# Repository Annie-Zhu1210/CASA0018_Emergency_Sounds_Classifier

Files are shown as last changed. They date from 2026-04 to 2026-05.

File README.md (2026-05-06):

#  Emergency Sounds Classifier
**CASA0018 Deep Learning for Sensor Networks — Final Project**

A wearable wristband for deaf and hearing-impaired people that detects urban emergency sounds in real time and alerts the user through vibration patterns.

<p align="center">
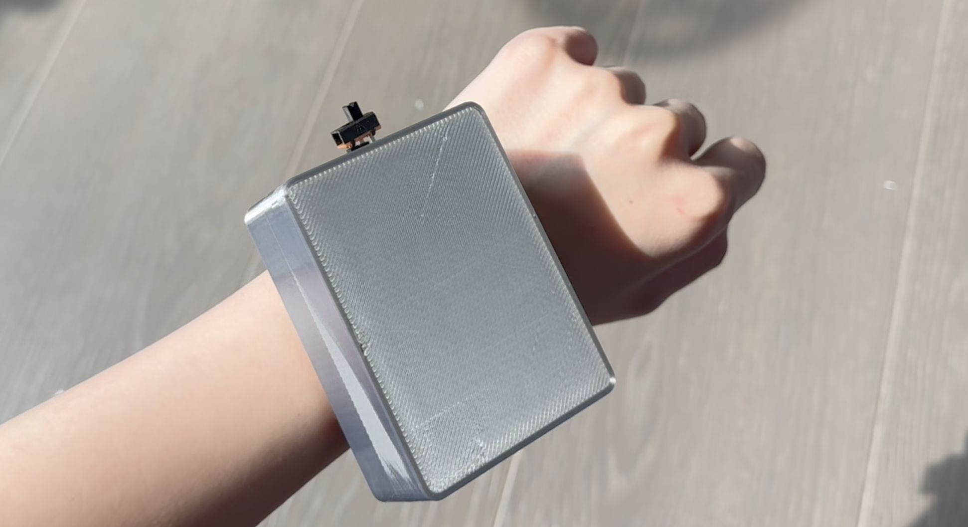
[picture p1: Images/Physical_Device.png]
Wristband
  <br>
</p>

---

## Overview

Approximately 1.57 billion people worldwide experience some degree of hearing loss. In urban environments, this creates real safety risks: failing to detect approaching emergency vehicles or car horns affects both pedestrians and drivers. This project deploys a trained audio classification model on an Arduino Nano 33 BLE Sense Lite, embedded in a 3D-printed wristband. The device listens continuously through its onboard MEMS microphone and triggers different vibration patterns depending on what it hears.

**Three classes are detected:**

| Class | Alert |
|---|---|
| `siren_hilo` | 1800ms sustained vibration pulse |
| `siren_wail&yelp` | 1800ms sustained vibration pulse |
| `carhorn` | Two 400ms pulses with 200ms gap |
| `background` | No vibration |

A confidence threshold of 0.70 is applied — the motor only activates when the model is sufficiently certain.

---

## Hardware

| Component | Spec | Role |
|---|---|---|
| Arduino Nano 33 BLE Sense Lite | 3.7V operating, VIN 4.5–21V | Microphone input, model inference, motor control |
| Vibration Motor Module | 3V–5.3V | Haptic alert output |
| 1000mAh 3.7V LiPo Battery | Nominal 3.7V | Wireless power |
| Adafruit bq24074 Charger | Load output 3.7–4.2V | USB-C charging, power regulation |
| Slide Switch | 0.3A 50V | On/off control |

**Wiring summary:**
- LiPo → bq24074 BATT port
- bq24074 LOAD → Arduino VIN (via slide switch)
- Arduino 3.3V → Motor VCC
- Arduino GND → Motor GND
- Arduino D9 → Motor IN

<p align="center">
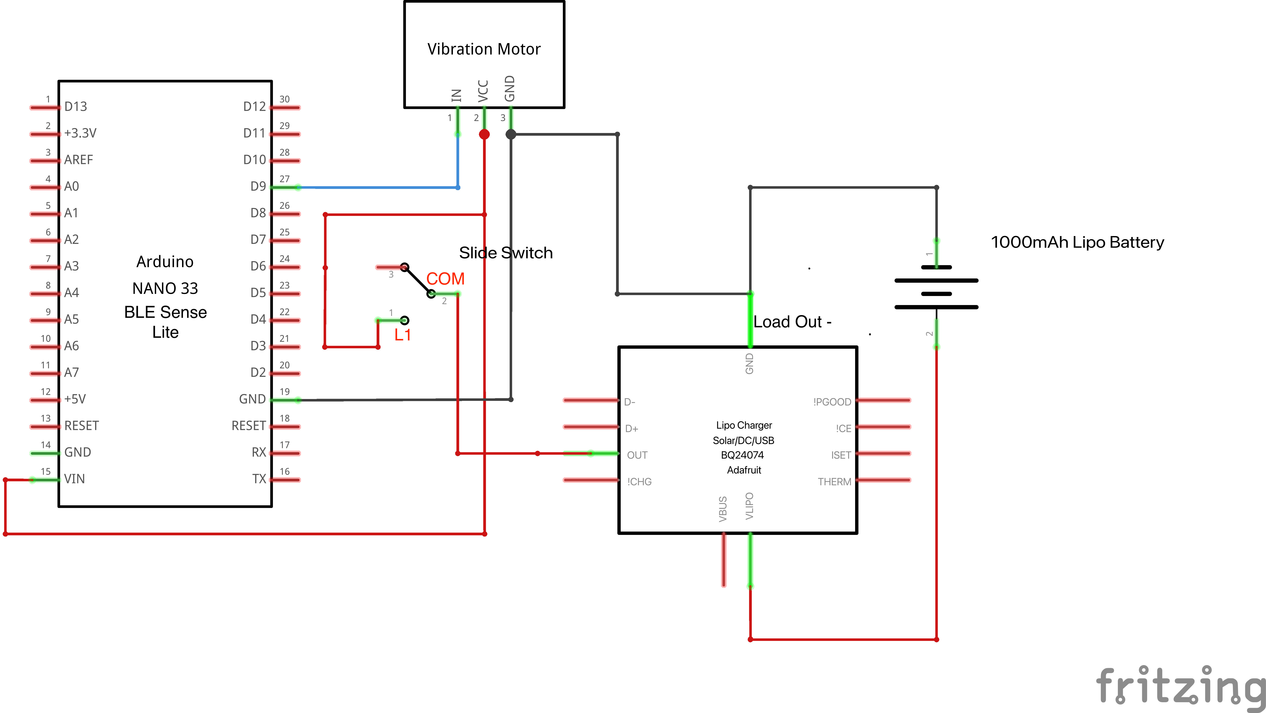
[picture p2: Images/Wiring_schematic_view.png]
Device wiring schematic
  <br>
  <sub>Device wiring schematic</sub>
</p>

**Estimated battery life:** ~83 hours assuming emergency sounds occur 10% of operating time (9mA idle, up to 39mA when motor fires).

---

## Enclosure

Hardware is housed in a custom 3D-printed box attached to a fabric scrunchy to simulate a wristband. The base is 1mm thick to maximise vibration transmission. Two rectangular apertures allow USB-C charging access and slide switch operation. Four corner screws secure the lid.

<p align="center">
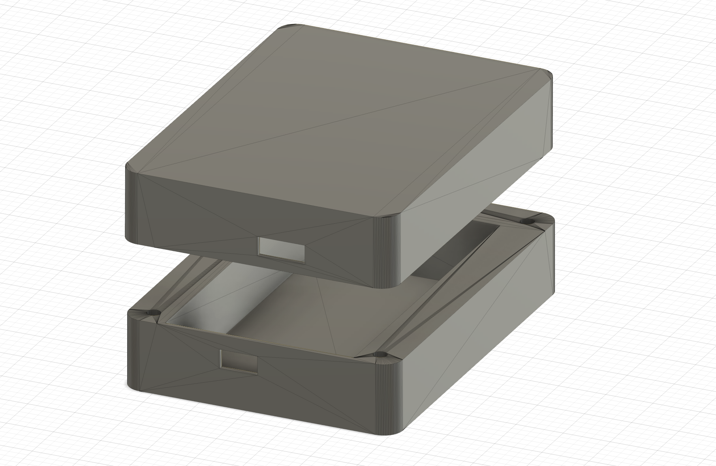
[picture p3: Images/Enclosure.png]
Enclosure 3D model
  <br>
  <sub>Enclosure 3D model</sub>
</p>

---

## Model

**Platform:** Edge Impulse (TensorFlow-based)

**Feature extraction:** Mel-filterbank Energy (MFE) — chosen over MFCCs because MFCCs' cepstral compression discards higher-frequency spectral detail, which is important for siren frequency sweep patterns.

**Architecture:** 1D Convolutional Neural Network
- Input: 2000ms audio window, resampled to 16kHz
- Two 1D conv/pool layers (16 filters, kernel size 3)
- Two dropout layers (rate 0.25)
- Flatten → output layer (4 classes)

**Deployment:** Quantised int8 TensorFlow Lite Arduino library
- RAM: 35.8KB (well within Arduino's 256KB budget)
- Latency: 522ms
- No accuracy loss vs. float32

**Final test accuracy: 94.26%**

| Class | Test Accuracy | F1 Score |
|---|---|---|
| background | 94.1% | 0.94 |
| carhorn | 72.7% | 0.84 |
| siren_hilo | 98.8% | 0.99 |
| siren_wail&yelp | 99.6% | 0.97 |

AUC-ROC: 1.00

---

## Experiment Log

Eight experiments were run iteratively. Key findings:

| Experiment | Key Change | Validation Acc | Test Acc |
|---|---|---|---|
| 1 | Baseline, 6 classes | 98.3% | 33.68% |
| 2 | Removed problematic background recording | 98.4% | 69.73% |
| 3 | 4000ms window, adjusted MFE, removed phaser | 98.1% | 50.26% |
| 4 | Merged wail & yelp, reverted to 2000ms | 97.5% | 91.65% |
| 5 | Increased first conv filters 8 → 16 | 98.3% | 94.54% |
| 6 | Added street-recorded carhorn samples | 99.5% | 70.71% |
| 7 | Added diverse background (traffic, wind) | 97.2% | 74.12% |
| 8 | Added wind and ambience samples — **final model** | 98.7% | 94.26% |

The single largest accuracy gain (+40 percentage points) came from merging `siren_wail` and `siren_yelp` into one class in Experiment 4 — achieved purely through label redesign, with no change to architecture or training parameters.

---

## Data

Audio samples were collected from two sources:

- **Personal recordings** — primarily around central London
- **Freesound.org** — supplementary samples (see [`SampleData/ATTRIBUTIONS.md`](SampleData/ATTRIBUTIONS.md) for full attribution)

All audio was resampled from 44.1kHz to 16kHz to match the Arduino microphone's capture rate before feature extraction.

**Class structure evolved across experiments** — starting with 6 classes (`background`, `carhorn`, `siren_hilo`, `siren_wail`, `siren_yelp`, `siren_phaser`) and consolidating to 4 by the final model. `siren_phaser` was removed due to insufficient data; `siren_wail` and `siren_yelp` were merged because they are acoustically inseparable at any tested window size and require the same user response.

---

## Repository Structure

```
├── Enclosure/
│   └── Bottom.STL                 # Enclosure bottom part
│   └── Top.STL                    # Enclosure top part
├── Siren_Classification/
│   └── Siren_Classification.ino   # Arduino sketch (inference + vibration logic)
├── SampleData/
│   └── ATTRIBUTIONS.md            # Full Freesound sample attribution
│   └── BackgroundNoise/
│   └── CarHorn/ 
│   └── Sirens/
│       └── Yelp/
│       └── Wail/
│       └── Hi-Lo/
│       └── Phaser/
├── model/
│   └── ei-emergencyvehiclesirens-arduino-1.0.1-impulse-6.zip  # Trained model
└── README.md
```

---

## How to Reproduce

### Option A: Use the pre-trained model (recommended)
 
1. Download the pre-trained Arduino library from [`model/ei-emergencyvehiclesirens-arduino-1.0.1-impulse-6.zip`](model/ei-emergencyvehiclesirens-arduino-1.0.1-impulse-6.zip)
2. In Arduino IDE, go to **Sketch → Include Library → Add .ZIP Library** and select the downloaded file
3. Open `Siren_Classification/Siren_Classification.ino` and upload to the Arduino Nano 33 BLE Sense Lite

### Option B: Retrain from scratch

1. **Set up Edge Impulse project** — create a new project and select Arduino Nano 33 BLE Sense as the target device
2. **Upload audio data** — use the Edge Impulse data acquisition tool or upload files directly; resample to 16kHz
3. **Configure impulse** — set window size to 2000ms; select MFE feature extraction with default parameters (frame length 0.02, frame stride 0.01, 40 filters, FFT length 256, noise floor −52dB)
4. **Set neural network architecture** — two 1D conv/pool layers with 16 filters, kernel size 3; dropout 0.25 after each; flatten; 4-class output
5. **Train and test** — target ~73/27 train/test split
6. **Deploy** — export as quantised int8 Arduino library
7. **Flash the sketch** — open `Siren_Classification/Siren_Classification.ino` in Arduino IDE, install the exported library, and upload to the board

---

## Limitations and Future Work

- **Carhorn false negatives (23.4%)** — a short horn in heavy traffic can produce a feature map acoustically similar to road ambience. A larger and more diverse carhorn dataset, particularly distant and overlapping sounds, would address this.
- **Enclosure attenuation** — testing showed that enclosing the device on the wrist reduces microphone sensitivity to distant sounds compared to open-air conditions. Aperture placement or microphone relocation could improve this.
- **Validation vs. test gap** — in experiments 6–7, high validation accuracy was misleading because validation samples did not reflect real-world recording conditions. The held-out test set is the only reliable performance indicator for this type of project.

---

## References

- Bubar et al. (2020). Emergency siren detection technology and hearing impairment: a systematized literature review. *Disability and Rehabilitation: Assistive Technology*.
- Chemnad & Othman (2024). Digital accessibility in the era of artificial intelligence. *Frontiers in Artificial Intelligence*.
- Haile et al. (2021). Hearing loss prevalence and years lived with disability, 1990–2019. *The Lancet*, 397(10278).
- Haytham Fayek (2016). *Speech Processing for Machine Learning: Filter banks, Mel-Frequency Cepstral Coefficients (MFCCs) and What’s In-Between*. 

- Fayek, H. (2016). Speech Processing for Machine Learning: Filter banks, MFCCs and What's In-Between.
- Luque et al. (2018). Optimal Representation of Anuran Call Spectrum in Environmental Monitoring Systems. *Sensors*, 18(6).
- Zayen & Groessing (2025). SafeDrive4Deaf. *Nafath*, 9(29).

---

## Generative AI Disclosure

Claude (Anthropic, Sonnet 4.6) was used during this project for research framing, technical guidance on Edge Impulse and wiring decisions, and report writing assistance. All experimental decisions, data collection, and results are the author's own work. All AI-assisted content was reviewed and verified before inclusion.

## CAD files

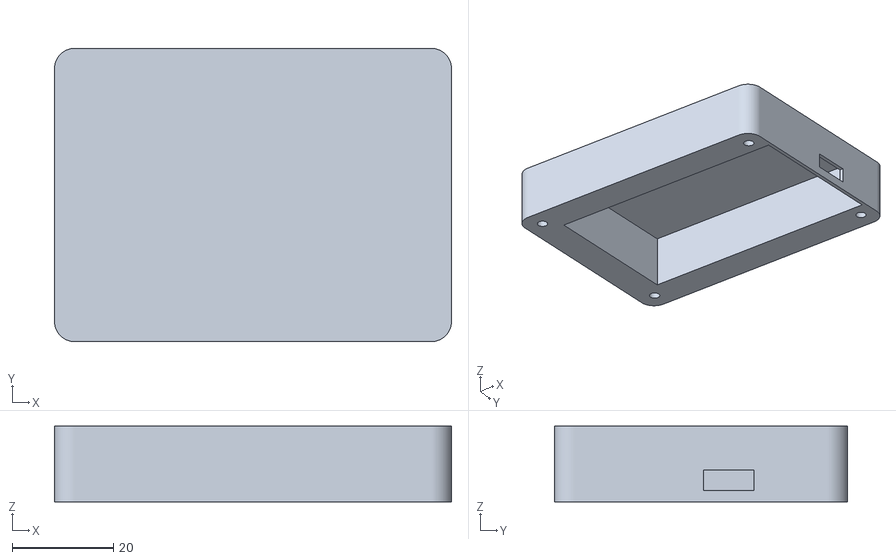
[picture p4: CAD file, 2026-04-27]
Enclosure/Top.STL
78.5 x 58.0 x 15.0

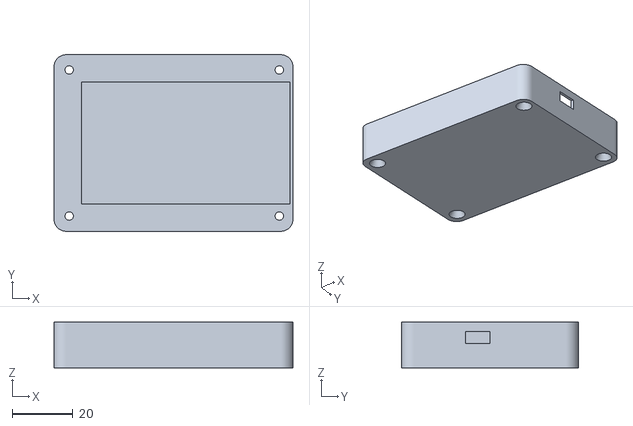
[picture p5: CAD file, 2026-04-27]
Enclosure/Bottom.STL
78.5 x 58.0 x 15.0

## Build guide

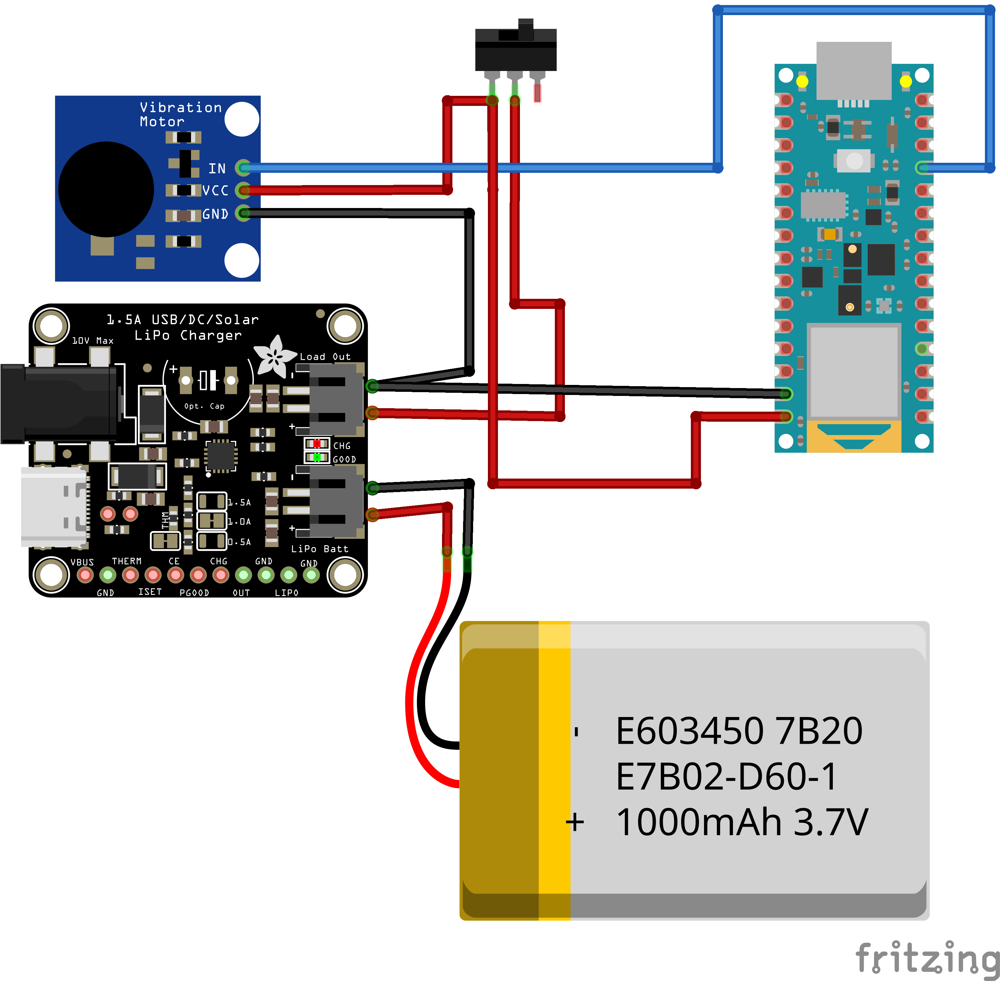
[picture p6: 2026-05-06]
Images/Wiring_breadboard_view.png

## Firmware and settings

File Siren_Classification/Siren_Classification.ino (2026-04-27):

#include <PDM.h>
#include <EmergencyVehicleSirens_inferencing.h>

#define MOTOR_PIN           9
#define CONFIDENCE_THRESHOLD 0.70

// Vibration patterns
#define MODERATE_DURATION   400
#define MODERATE_REPEATS    2
#define INTENSE_DURATION    1800
#define INTENSE_REPEATS     1

/* Audio buffer */
typedef struct {
  int16_t *buffer;
  uint8_t buf_ready;
  uint32_t buf_count;
  uint32_t n_samples;
} inference_t;

static inference_t inference;
static signed short sampleBuffer[2048];
static bool debug_nn = false;

void vibrate_moderate() {
  for (int i = 0; i < MODERATE_REPEATS; i++) {
    digitalWrite(MOTOR_PIN, HIGH);
    delay(MODERATE_DURATION);
    digitalWrite(MOTOR_PIN, LOW);
    delay(200);
  }
}

void vibrate_intense() {
  for (int i = 0; i < INTENSE_REPEATS; i++) {
    digitalWrite(MOTOR_PIN, HIGH);
    delay(INTENSE_DURATION);
    digitalWrite(MOTOR_PIN, LOW);
    delay(200);
  }
}

static void pdm_data_ready_inference_callback(void) {
  int bytesAvailable = PDM.available();
  int bytesRead = PDM.read((char *)&sampleBuffer[0], bytesAvailable);

  if (inference.buf_ready == 0) {
    for (int i = 0; i < bytesRead >> 1; i++) {
      inference.buffer[inference.buf_count++] = sampleBuffer[i];
      if (inference.buf_count >= inference.n_samples) {
        inference.buf_count = 0;
        inference.buf_ready = 1;
        break;
      }
    }
  }
}

static bool microphone_inference_start(uint32_t n_samples) {
  inference.buffer = (int16_t *)malloc(n_samples * sizeof(int16_t));
  if (inference.buffer == NULL) return false;

  inference.buf_count = 0;
  inference.n_samples = n_samples;
  inference.buf_ready = 0;

  PDM.onReceive(pdm_data_ready_inference_callback);
  PDM.setBufferSize(4096);

  if (!PDM.begin(1, EI_CLASSIFIER_FREQUENCY)) {
    ei_printf("ERR: Failed to start PDM!\r\n");
    microphone_inference_end();
    return false;
  }

  PDM.setGain(127);
  return true;
}

static bool microphone_inference_record(void) {
  inference.buf_ready = 0;
  inference.buf_count = 0;

  uint32_t start = millis();
  while (inference.buf_ready == 0) {
    if (millis() - start > 5000) {
      ei_printf("ERR: Audio capture timed out\r\n");
      return false;
    }
    delay(10);
  }
  return true;
}

static int microphone_audio_signal_get_data(size_t offset, size_t length, float *out_ptr) {
  numpy::int16_to_float(&inference.buffer[offset], out_ptr, length);
  return 0;
}

static void microphone_inference_end(void) {
  PDM.end();
  free(inference.buffer);
}

void setup() {
  Serial.begin(115200);
  pinMode(MOTOR_PIN, OUTPUT);
  digitalWrite(MOTOR_PIN, LOW);

  // Quick motor test on boot
  Serial.println("Motor test...");
  vibrate_moderate();
  delay(500);

  Serial.println("Edge Impulse Inference - Emergency Sound Classifier");
  Serial.println("Classes: background | carhorn | siren_hilo | siren_wail&yelp");

  if (!microphone_inference_start(EI_CLASSIFIER_RAW_SAMPLE_COUNT)) {
    ei_printf("ERR: Failed to setup audio sampling\r\n");
    while (1);
  }

  Serial.println("Listening...");
}

void loop() {
  if (!microphone_inference_record()) {
    ei_printf("ERR: Failed to record audio...\r\n");
    return;
  }

  signal_t signal;
  signal.total_length = EI_CLASSIFIER_RAW_SAMPLE_COUNT;
  signal.get_data = &microphone_audio_signal_get_data;

  ei_impulse_result_t result = { 0 };
  EI_IMPULSE_ERROR r = run_classifier(&signal, &result, debug_nn);

  if (r != EI_IMPULSE_OK) {
    ei_printf("ERR: Failed to run classifier (%d)\r\n", r);
    return;
  }

  // Print all predictions
  ei_printf("Predictions (DSP: %d ms., Classification: %d ms.):\r\n",
            result.timing.dsp, result.timing.classification);
  for (size_t ix = 0; ix < EI_CLASSIFIER_LABEL_COUNT; ix++) {
    ei_printf("    %s: %.5f\r\n",
              result.classification[ix].label,
              result.classification[ix].value);
  }

  // Find highest confidence class
  float max_val = 0.0;
  const char* max_label = "";

  for (size_t ix = 0; ix < EI_CLASSIFIER_LABEL_COUNT; ix++) {
    if (result.classification[ix].value > max_val) {
      max_val = result.classification[ix].value;
      max_label = result.classification[ix].label;
    }
  }

  // Check for siren (either subtype) and merge in code 
  bool is_siren = (
    (strcmp(max_label, "siren_hilo") == 0 ||
     strcmp(max_label, "siren_wail&yelp") == 0) &&
    max_val >= CONFIDENCE_THRESHOLD
  );

  bool is_carhorn = (
    strcmp(max_label, "carhorn") == 0 &&
    max_val >= CONFIDENCE_THRESHOLD
  );

  if (is_siren) {
    ei_printf(">> EMERGENCY SIREN detected (%.2f) - intensive vibration\r\n", max_val);
    vibrate_intense();
  } else if (is_carhorn) {
    ei_printf(">> CAR HORN detected (%.2f) - moderate vibration\r\n", max_val);
    vibrate_moderate();
  } else {
    ei_printf(">> Background / below threshold (%.2f)\r\n", max_val);
  }
}

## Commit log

2026-04-25 Sample Audio Data
2026-04-25 New sample data
    A new background noise audio was added to replace the record2 audio, eliminating the confusion from the pedestrian crossing siren for the model
2026-04-25 Added new sample data
2026-04-27 Added car horn samples
2026-04-27 Added more back corn and background traffic noise samples
2026-04-27 Added more background samples
2026-04-27 Added Enclosure models
    [Button.STL, Top.STL]
2026-04-27 Add vibration motor responses for carhorn and siren classes
    [Siren_Classification.ino]
2026-05-06 Added attribution text for sample data
2026-05-06 Renamed file
    [Bottom.STL]
